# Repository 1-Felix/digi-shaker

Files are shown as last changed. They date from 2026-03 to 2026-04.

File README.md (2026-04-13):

<p align="center">
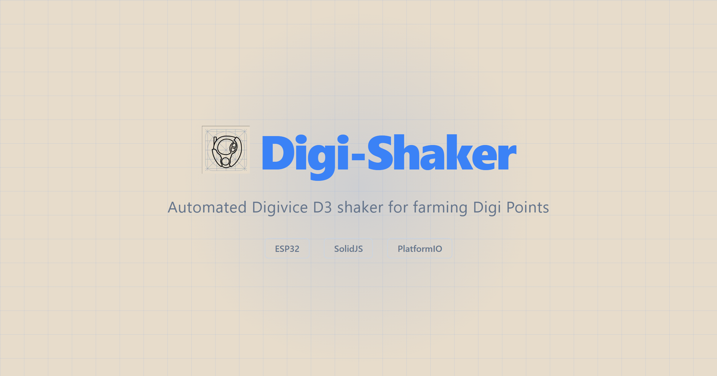
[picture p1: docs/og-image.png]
Digi-Shaker
  
</p>

<p align="center">
  <strong>Automated Digivice D3 shaker for farming Digi Points — controlled via web dashboard.</strong>
</p>

<p align="center">
  
</p>

---

An ESP32-powered physical device that shakes a Digivice D3 (Version 3 Japan edition) to farm Digi Points. Part of a larger reverse engineering project for the D3 game.

Features a 3D printed arm that holds the device, driven by an MG996R servo. Control via web dashboard with configurable shake patterns, calibration, and step tracking.

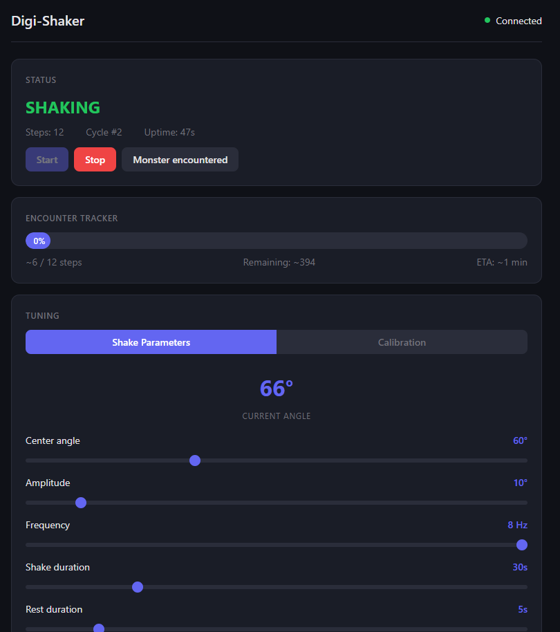
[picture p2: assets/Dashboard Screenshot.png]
Dashboard


Configure shake patterns, frequency, duration and rest periods from the web dashboard.

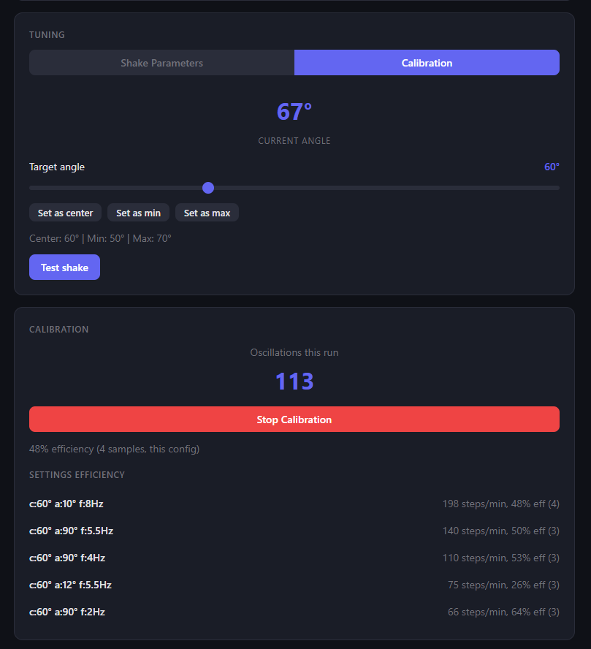
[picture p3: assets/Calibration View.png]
Calibration View


Step counting for accurate Digi Point tracking.

## Hardware

- **ESP32** (NodeMCU CH340 USB-C)
- **MG996R servo** driven by 3D printed arm cradle (in `models/`)

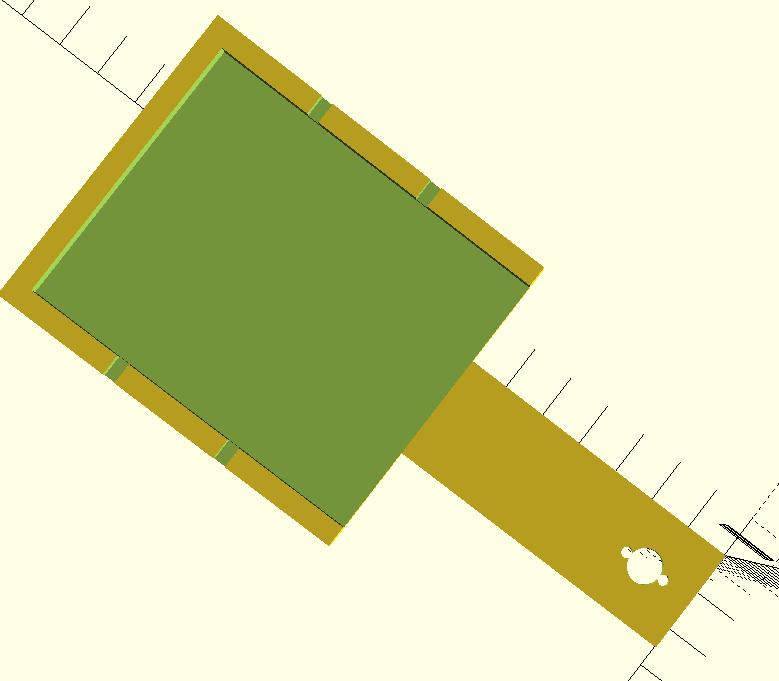
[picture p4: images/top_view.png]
Top View

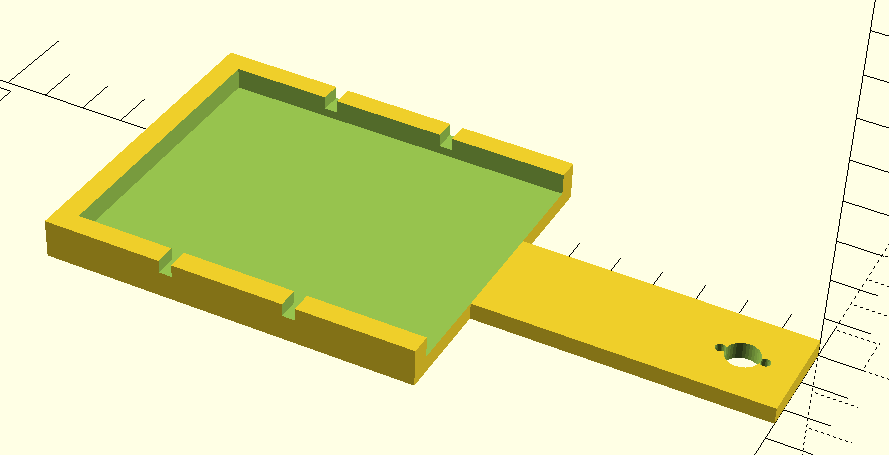
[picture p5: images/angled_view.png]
Angled View


<details>
<summary>3D printed parts</summary>

- Servo arm cradle (designed for MG996R)
- Device holder/clip
- Mounting base

Models in `models/` — designed for FDM printing with PLA.

</details>

## Quick Start

### 1. Flash the firmware

```bash
cd firmware
pio run upload
```

Configure WiFi credentials in `firmware/include/wifi_credentials.h` before building.

### 2. Run the dashboard

```bash
cd dashboard/ui
bun install
bun dev
```

Open http://localhost:5173 — the dashboard auto-discovers the device via mDNS or connect directly to `http://<device-ip>:81`.

### 3. Configure and start shaking

Set shake frequency, amplitude, and duration from the dashboard. The device will shake in cycles with rest periods.

## WebSocket Protocol

The dashboard communicates with the device over WebSocket on port 81.

```
┌──────────────┐    WS :81    ┌─────────────┐
│  Dashboard  │ ◀───────────▶ │ ESP32       │
│  (SolidJS)  │              │ + Servo     │
└──────────────┘              └─────────────┘
```

Messages are JSON — see `openspec/changes/remote-dashboard/specs/websocket-protocol/spec.md` for the full protocol spec.

## Architecture

```
┌─────────────────────────────────────────────────────────────┐
│                      Web Dashboard                         │
│  ┌─────────────┐  ┌──────────────┐  ┌─────────────────┐  │
│  │ StatusPanel │  │ ControlPanel │  │ CalibrationView  │  │
│  └─────────────┘  └──────────────┘  └─────────────────┘  │
└────────────────────────────┬────────────────────────────────┘
                             │ WebSocket
                             ▼
┌─────────────────────────────────────────────────────────────┐
│                         ESP32                               │
│  ┌──────────────┐  ┌───────────────┐  ┌────────────────┐  │
│  │ StateMachine │  │ ServoControl  │  │ StepCounter    │  │
│  │ IDLE/SHAKING │  │ MG996R driver │  │ Zero-crossing  │  │
│  └──────────────┘  └───────────────┘  └────────────────┘  │
│         │                  │                  │            │
│         └──────────────────┼──────────────────┘            │
│                            ▼                               │
│                    ┌─────────────┐                         │
│                    │   Servo     │ ◀── shakes D3 device    │
│                    └─────────────┘                         │
└─────────────────────────────────────────────────────────────┘
```

## Tech Stack

- **ESP32** — microcontroller
- **PlatformIO** — firmware build
- **Arduino** — firmware framework
- **SolidJS** — dashboard UI
- **WebSockets** — real-time control
- **OpenSCAD** — 3D models

## Development

```bash
# Firmware
cd firmware
pio run upload
pio monitor

# Dashboard
cd dashboard/ui
bun dev
```

## License

MIT

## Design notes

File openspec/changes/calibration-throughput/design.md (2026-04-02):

## Context

The calibration system stores efficiency ratio (actualSteps / oscillationCount) per config. The Settings Efficiency table sorts by ratio. But the user optimizes for **time-to-encounter** — the metric that matters is steps/minute throughput, not per-oscillation efficiency.

Currently, throughput can be computed from existing data: `freq × ratio × 60 × (shakeDur / (shakeDur + restDur))`. But this is theoretical — it doesn't account for servo lag, startup time, or physical constraints at high frequencies. Storing measured shaking duration per sample enables actual throughput measurement.

## Goals / Non-Goals

**Goals:**
- Compute and display throughput (steps/min) for all existing calibration data using config parameters
- Track elapsed shaking time (excluding rest/idle) on new calibration samples for measured throughput
- Make throughput the primary sort/comparison metric in the UI
- Use measured throughput when available, fall back to computed

**Non-Goals:**
- Firmware changes (ESP32 already broadcasts state in status messages)
- Changing the calibration collection workflow (start/stop/submit stays the same)
- Historical backfill of shaking duration for existing samples

## Decisions

### 1. Track shaking time on the backend, not the frontend

The backend already receives every ESP32 status update with `state` field. During a calibration run, the backend can accumulate time spent in `shaking` state by tracking state transitions. This is more accurate than frontend timing (no network latency skew) and requires no protocol changes.

**Alternative**: Frontend tracks time via `status.state` — rejected because backend already has the status stream and can track more precisely without round-trip latency.

### 2. Nullable `shaking_duration_s` column

Add `shaking_duration_s REAL` (nullable) to the `calibrations` table. Existing rows remain NULL. When duration is available, compute `measured_throughput = actualSteps / (shaking_duration_s / 60)`. When NULL, fall back to computed throughput from config params.

**Alternative**: Separate throughput table — rejected as unnecessary complexity for a single additional column.

### 3. Backend tracks calibration state per browser client

The calibration start/stop is initiated by a specific browser client. The backend needs to track which client is calibrating, when they started, and accumulate shaking seconds. A simple `Map<ws, CalibrationState>` keyed by WebSocket connection handles this.

State tracked per calibration run:
- `startedAt`: timestamp
- `shakingMs`: accumulated milliseconds in shaking state
- `lastShakingStart`: timestamp when current shaking interval began (null if resting/idle)

On each ESP32 status update, for any active calibration: if state transitioned to `shaking`, record `lastShakingStart`. If state transitioned away from `shaking`, add elapsed to `shakingMs`.

### 4. Throughput computation for existing data

For samples without `shaking_duration_s`:
```
computedThroughput = frequency × avgRatio × 60 × (shakeDuration / (shakeDuration + restDuration))
```

This uses the config params stored on the calibration sample and the config's average ratio. It's a per-config metric displayed in the efficiency table.

### 5. Frontend sends `startCalibration` / `stopCalibration` messages

New message types so the backend knows when to start/stop tracking shaking time. The existing `calibration` submit message includes the accumulated duration from the backend's tracking.

## Risks / Trade-offs

- **[Stale tracking on disconnect]** → If browser disconnects mid-calibration, the tracking state is lost. Acceptable since the user would need to restart calibration anyway.
- **[Clock precision]** → Using `Date.now()` for millisecond tracking. Sufficient for 30s+ calibration runs where we need ~1s accuracy.
- **[Computed vs measured mismatch]** → Users may see different throughput numbers for old (computed) vs new (measured) samples of the same config. The UI should indicate which is which.

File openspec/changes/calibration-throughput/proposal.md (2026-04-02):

## Why

The current calibration system only measures efficiency (steps per oscillation ratio), but the metric that actually matters is **throughput** — how many real steps the Digivice registers per minute. A config with lower efficiency but higher frequency can produce more steps/min than a high-efficiency slow config. Without throughput data, the user can't meaningfully compare settings to find the fastest path to an encounter.

## What Changes

- Compute and display **steps/minute throughput** for each calibration config, derived from existing data (frequency × ratio × duty cycle)
- Store **elapsed shaking time** (excluding rest/idle periods) on new calibration samples for measured throughput
- Sort the Settings Efficiency table by throughput (steps/min) instead of efficiency ratio
- Show throughput as the primary metric in the calibration comparison UI, with efficiency as secondary

## Capabilities

### New Capabilities
- `calibration-throughput`: Throughput calculation, storage, and display for calibration configs — both computed (from existing data) and measured (from new samples with tracked duration)

### Modified Capabilities

## Impact

- **Database**: `calibrations` table gets a new `shaking_duration_s` column (nullable for existing rows)
- **Backend**: Server tracks shaking time during calibration runs via ESP32 state transitions; enriches calibration responses with throughput
- **Frontend**: CalibrationPanel and EncounterTracker updated to display throughput; efficiency table re-sorted
- **No firmware changes** — ESP32 already broadcasts state in status messages

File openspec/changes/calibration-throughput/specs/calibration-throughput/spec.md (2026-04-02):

## ADDED Requirements

### Requirement: Shaking duration tracking
The system SHALL track elapsed shaking time (time spent in `shaking` state only, excluding rest and idle periods) during calibration runs. The backend SHALL start tracking when it receives a `startCalibration` message and stop when it receives a `stopCalibration` message from the same browser client.

#### Scenario: Normal calibration run with shaking and resting
- **WHEN** a calibration run spans 3 shake cycles (30s each) with 5s rest between them
- **THEN** the tracked shaking duration SHALL be ~90 seconds (excluding the 10s of rest)

#### Scenario: Calibration run where shaker is stopped mid-shake
- **WHEN** the user stops calibration while the servo is in shaking state
- **THEN** the system SHALL include the partial shaking interval in the total duration

#### Scenario: Browser disconnects during calibration
- **WHEN** the browser WebSocket disconnects while a calibration is active
- **THEN** the tracking state SHALL be discarded (no partial data stored)

### Requirement: Shaking duration storage
The system SHALL store `shaking_duration_s` (real, nullable) in the calibrations table. New calibration samples submitted via `stopCalibration` SHALL include the tracked shaking duration. Existing samples without duration SHALL have NULL for this field.

#### Scenario: New calibration sample with duration
- **WHEN** a calibration sample is submitted after a tracked run of 90 seconds of shaking
- **THEN** the sample SHALL be stored with `shaking_duration_s = 90`

#### Scenario: Existing sample without duration
- **WHEN** the system reads a calibration sample that was created before this feature
- **THEN** `shaking_duration_s` SHALL be NULL

### Requirement: Throughput computation
The system SHALL compute throughput (steps per minute) for each calibration config. When `shaking_duration_s` is available, throughput SHALL be `actualSteps / (shaking_duration_s / 60)`. When not available, throughput SHALL be computed as `frequency × avgRatio × 60 × (shakeDuration / (shakeDuration + restDuration))` using the config's stored parameters.

#### Scenario: Measured throughput from tracked duration
- **WHEN** a config has samples with `shaking_duration_s` recorded
- **THEN** throughput SHALL be calculated from the measured duration: `sum(actualSteps) / (sum(shaking_duration_s) / 60)`

#### Scenario: Computed throughput from config parameters
- **WHEN** a config has only samples without `shaking_duration_s` (legacy data)
- **THEN** throughput SHALL be estimated as `frequency × avgRatio × 60 × (shakeDuration / (shakeDuration + restDuration))`

### Requirement: Efficiency table sorted by throughput
The Settings Efficiency table SHALL sort configs by throughput (steps/min) descending instead of by efficiency ratio. Each config entry SHALL display both throughput and efficiency.

#### Scenario: Two configs with different throughput rankings
- **WHEN** Config A has 70% efficiency at 4Hz (throughput ~168 steps/min) and Config B has 40% efficiency at 8Hz (throughput ~192 steps/min)
- **THEN** Config B SHALL appear above Config A in the table

#### Scenario: Throughput display format
- **WHEN** a config has throughput of 168.4 steps/min and 70% efficiency
- **THEN** the entry SHALL display throughput rounded to nearest integer and efficiency as percentage (e.g., "168 steps/min, 70% eff")

### Requirement: Calibration WebSocket protocol additions
The browser SHALL send `startCalibration` message when beginning a calibration run and `stopCalibration` message when ending it. The backend SHALL respond to `stopCalibration` with the accumulated shaking duration. The existing `calibration` submit message SHALL accept an optional `shakingDurationS` field.

#### Scenario: Start calibration message
- **WHEN** the user clicks "Start Calibration"
- **THEN** the browser SHALL send `{ type: "startCalibration" }` to the backend

#### Scenario: Stop calibration message and response
- **WHEN** the user clicks "Stop Calibration"
- **THEN** the browser SHALL send `{ type: "stopCalibration" }` and the backend SHALL respond with `{ type: "calibrationStopped", shakingDurationS: <number> }`

#### Scenario: Submit with duration
- **WHEN** the user submits a calibration with actual steps after receiving the shaking duration
- **THEN** the `calibration` message SHALL include `shakingDurationS` alongside `oscillationCount` and `actualSteps`

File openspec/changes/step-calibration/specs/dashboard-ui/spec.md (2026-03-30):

## ADDED Requirements

### Requirement: Calibration panel
The dashboard SHALL include a calibration panel for measuring and recording the step registration ratio.

#### Scenario: Start calibration
- **WHEN** the user clicks "Start Calibration"
- **THEN** the system SHALL record the current stepCount, start the shaker if idle, and begin tracking oscillations

#### Scenario: Stop calibration
- **WHEN** the user clicks "Stop Calibration" during a calibration run
- **THEN** the shaker SHALL stop and the UI SHALL display the oscillation count (current stepCount minus start stepCount) and prompt for actual Digivice steps

#### Scenario: Submit actual steps
- **WHEN** the user enters the actual step count and clicks "Submit"
- **THEN** the calibration sample SHALL be sent to the backend and a success toast SHALL appear

#### Scenario: Validation
- **WHEN** the user submits an actual step count that is zero, negative, or greater than the oscillation count
- **THEN** the UI SHALL show an error and not submit

### Requirement: Current ratio display
The calibration panel SHALL display the current calibration ratio and how it was determined.

#### Scenario: Config-specific ratio
- **WHEN** calibrations exist for the current parameter set
- **THEN** the panel SHALL display the ratio and sample count for the current config

#### Scenario: Global fallback display
- **WHEN** using the global average fallback
- **THEN** the panel SHALL indicate that the ratio is a global average, not config-specific

### Requirement: Settings efficiency comparison
The calibration panel SHALL display a comparison of calibration efficiency across different parameter configurations.

#### Scenario: Multiple configs calibrated
- **WHEN** calibration samples exist for more than one parameter configuration
- **THEN** the panel SHALL show each config with its average efficiency percentage and sample count, sorted by efficiency

#### Scenario: Single config
- **WHEN** calibrations exist for only one config
- **THEN** only that config's efficiency SHALL be shown

### Requirement: Calibration history management
The calibration panel SHALL allow viewing and deleting individual calibration samples.

#### Scenario: View samples
- **WHEN** the user expands a config in the efficiency comparison
- **THEN** individual samples SHALL be visible with their oscillation count, actual steps, and ratio

#### Scenario: Delete sample
- **WHEN** the user clicks delete on a calibration sample
- **THEN** the sample SHALL be removed and the ratio recalculated

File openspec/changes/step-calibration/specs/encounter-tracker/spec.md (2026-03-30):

## MODIFIED Requirements

### Requirement: Encounter probability display
The dashboard SHALL display the cumulative probability of a monster encounter based on the **calibrated** step count (raw oscillations multiplied by the calibration ratio).

#### Scenario: Below first threshold
- **WHEN** the calibrated step count is below 400
- **THEN** the encounter probability SHALL display as 0% with a progress bar showing distance to 400

#### Scenario: Cumulative probability at thresholds
- **WHEN** the calibrated step count reaches 400, 450, 500, or 550
- **THEN** the encounter probability SHALL display the cumulative value (40%, 60%, 90%, 100%)

#### Scenario: Display raw and calibrated
- **WHEN** a calibration ratio other than 1.0 is active
- **THEN** the display SHALL show both calibrated and raw counts (e.g., "~87 / 120 steps")

#### Scenario: No calibration
- **WHEN** no calibration data exists (ratio is 1.0)
- **THEN** the display SHALL show the raw step count without a calibrated value

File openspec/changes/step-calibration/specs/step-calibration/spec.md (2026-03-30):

## ADDED Requirements

### Requirement: Calibration data persistence
The backend SHALL store calibration samples in a `calibrations` SQLite table with columns: id, created_at, oscillation_count, actual_steps, ratio, center_angle, amplitude, frequency.

#### Scenario: Table creation
- **WHEN** the backend starts and the calibrations table does not exist
- **THEN** it SHALL be created with the schema above

#### Scenario: Sample storage
- **WHEN** a calibration sample is submitted with oscillation_count and actual_steps
- **THEN** the backend SHALL store it with the current shake parameters and computed ratio (actual_steps / oscillation_count)

### Requirement: Calibration ratio lookup
The backend SHALL provide a calibration ratio using a three-tier fallback: exact config match, global average, or 1.0.

#### Scenario: Exact config match
- **WHEN** calibration samples exist for the current center_angle, amplitude, and frequency
- **THEN** the ratio SHALL be the average of matching samples' ratios

#### Scenario: Global fallback
- **WHEN** no calibration samples match the current config but other samples exist
- **THEN** the ratio SHALL be the average of all samples' ratios

#### Scenario: No calibrations
- **WHEN** no calibration samples exist at all
- **THEN** the ratio SHALL be 1.0

### Requirement: Calibration submission via WebSocket
The backend SHALL accept calibration submissions over the browser WebSocket.

#### Scenario: Submit calibration
- **WHEN** the browser sends `{ "type": "calibration", "oscillationCount": <number>, "actualSteps": <number> }`
- **THEN** the backend SHALL store the sample with the current ESP32 parameters and respond with the updated ratio

### Requirement: Calibration history via WebSocket
The backend SHALL provide calibration history and current ratio to browser clients.

#### Scenario: Request calibration data
- **WHEN** the browser sends `{ "type": "getCalibration" }`
- **THEN** the backend SHALL respond with the current ratio, sample count, and per-config efficiency breakdown

#### Scenario: Ratio included in status
- **WHEN** the backend enriches an ESP32 status message for browser clients
- **THEN** it SHALL include the current calibration ratio and calibrated step count

### Requirement: Delete calibration sample
The backend SHALL support deleting individual calibration samples.

#### Scenario: Delete sample
- **WHEN** the browser sends `{ "type": "deleteCalibration", "id": <number> }`
- **THEN** the backend SHALL remove that sample and respond with the updated ratio

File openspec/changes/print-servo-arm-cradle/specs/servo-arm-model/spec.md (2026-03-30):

## ADDED Requirements

### Requirement: Parametric OpenSCAD model
The project SHALL include an OpenSCAD file at `models/servo-arm-cradle.scad` that generates a 3D-printable servo arm with integrated Digivice cradle. All key dimensions SHALL be defined as parameters at the top of the file.

#### Scenario: Adjustable parameters
- **WHEN** a user opens the .scad file
- **THEN** the following parameters SHALL be editable at the top of the file: `digivice_length` (default 75), `digivice_width` (default 60), `digivice_depth` (default 20), `arm_length` (default 100), `arm_width` (default 25), `arm_thickness` (default 4), `wall_height` (default 5), `wall_thickness` (default 5), `clearance` (default 1), `horn_screw_spacing` (default 10), `horn_screw_diameter` (default 2.5)

#### Scenario: Preview renders correctly
- **WHEN** a user presses F5 (preview) in OpenSCAD
- **THEN** the model SHALL render a single solid body showing the arm, cradle walls, and servo horn mount holes

### Requirement: Servo horn mount
The arm SHALL include a flat mounting area on one end with two through-holes spaced to match the MG996R stock servo horn screw pattern. The holes SHALL have a diameter of 2.5mm (for M2 screws with clearance).

#### Scenario: Horn screw holes are present
- **WHEN** the STL is sliced in a slicer
- **THEN** two cylindrical through-holes SHALL be visible on the servo end, spaced 10mm apart (center to center), each 2.5mm in diameter

### Requirement: Digivice cradle pocket
The arm SHALL include a rectangular pocket on the opposite end from the servo mount. The pocket inner dimensions SHALL be `digivice_length + 2*clearance` by `digivice_width + 2*clearance`. Walls SHALL rise `wall_height` mm above the arm surface on three sides, with one short side open for sliding the device in.

#### Scenario: Digivice fits in pocket
- **WHEN** a Digivice D3 V3 (75 x 60 mm) is placed into the printed cradle
- **THEN** it SHALL fit with approximately 1mm clearance on each side

#### Scenario: One open side for insertion
- **WHEN** viewing the cradle from above
- **THEN** one of the short sides (60mm side) SHALL have no wall, allowing the Digivice to slide in

### Requirement: Rubber band retention slots
The cradle walls SHALL include notches/slots to allow rubber bands to be wrapped around the cradle to secure the Digivice. There SHALL be at least two slots on each long wall.

#### Scenario: Rubber band slots present
- **WHEN** examining the printed cradle walls
- **THEN** each long wall SHALL have at least two U-shaped notches (approximately 3mm wide, 3mm deep) cut into the top edge of the wall

### Requirement: Print-friendly geometry
The model SHALL be designed to print flat on a build plate without supports. All surfaces SHALL be flat-bottomed. No overhangs SHALL exceed 45 degrees.

#### Scenario: No supports needed in slicer
- **WHEN** the STL is imported into a slicer (e.g., Cura, PrusaSlicer) with the flat bottom on the build plate
- **THEN** the slicer SHALL report no support material needed at default overhang settings (45°)

### Requirement: STL export
The project SHALL include a pre-exported STL file at `models/servo-arm-cradle.stl` ready for direct slicing and printing.

#### Scenario: STL file is valid
- **WHEN** the STL file is opened in a slicer
- **THEN** it SHALL be a valid, manifold mesh with no errors

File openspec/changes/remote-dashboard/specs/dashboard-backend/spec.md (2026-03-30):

## ADDED Requirements

### Requirement: Hono HTTP server
The dashboard backend SHALL run a Hono server on Bun, listening on port 3000 (configurable via `PORT` environment variable).

#### Scenario: Server starts
- **WHEN** the dashboard application starts
- **THEN** the Hono server SHALL listen on the configured port and serve the static SolidJS build files

#### Scenario: Static file serving
- **WHEN** a browser requests `/` or any UI route
- **THEN** the server SHALL serve the SolidJS application's `index.html` and associated assets

### Requirement: ESP32 WebSocket client
The backend SHALL maintain a WebSocket connection to the ESP32 as a client.

#### Scenario: Connect to ESP32
- **WHEN** the backend starts
- **THEN** it SHALL connect to the ESP32 WebSocket server at the address specified by the `ESP32_HOST` environment variable (default: `digi-shaker.local`) on port 81

#### Scenario: Reconnection
- **WHEN** the WebSocket connection to the ESP32 drops
- **THEN** the backend SHALL reconnect with exponential backoff starting at 1 second, capping at 30 seconds

#### Scenario: Connection status tracking
- **WHEN** the ESP32 connection state changes (connected/disconnected)
- **THEN** the backend SHALL include the connection status in messages to browser clients

### Requirement: Browser WebSocket server
The backend SHALL accept WebSocket connections from browser dashboard clients.

#### Scenario: Browser connects
- **WHEN** a browser client connects to `ws://<host>:3000/ws`
- **THEN** the backend SHALL accept the connection and begin relaying ESP32 status messages

#### Scenario: Multiple browsers
- **WHEN** multiple browser clients connect simultaneously
- **THEN** all clients SHALL receive the same status broadcasts

#### Scenario: Command relay
- **WHEN** a browser client sends a command message
- **THEN** the backend SHALL forward it to the ESP32 over the ESP32 WebSocket connection

#### Scenario: ESP32 offline
- **WHEN** a browser sends a command but the ESP32 is disconnected
- **THEN** the backend SHALL respond with an error message: `{ "type": "error", "message": "ESP32 not connected" }`

### Requirement: Status enrichment
The backend SHALL enrich ESP32 status messages with encounter probability data before relaying to browsers.

#### Scenario: Probability calculation
- **WHEN** the backend receives a status message from the ESP32
- **THEN** it SHALL calculate the cumulative encounter probability based on shake count and append it to the message before sending to browsers

#### Scenario: Configurable thresholds
- **WHEN** encounter probability thresholds are defined in the backend configuration
- **THEN** the backend SHALL use those thresholds for probability calculation instead of hardcoded defaults

### Requirement: SQLite stats persistence
The backend SHALL persist shake session data in a SQLite database using `bun:sqlite`.

#### Scenario: Database initialization
- **WHEN** the backend starts and no database file exists at `data/shaker.sqlite`
- **THEN** it SHALL create the database and initialize the schema

#### Scenario: Session recording
- **WHEN** a shake cycle completes (ESP32 transitions from SHAKING to RESTING)
- **THEN** the backend SHALL record the session with: timestamp, shake count at start, shake count at end, duration, and active parameters

#### Scenario: Counter reset recording
- **WHEN** the user resets the shake counter (indicating a monster encounter)
- **THEN** the backend SHALL record the encounter with: timestamp and total shakes before reset

#### Scenario: History query
- **WHEN** a browser client requests session history
- **THEN** the backend SHALL query the database and return sessions grouped by day with totals

### Requirement: Last-known config resend
The backend SHALL persist the last-known parameter configuration and resend it to the ESP32 on reconnection.

#### Scenario: Config persistence
- **WHEN** the user changes parameters via the dashboard
- **THEN** the backend SHALL store the parameters in the database

#### Scenario: Resend on reconnect
- **WHEN** the ESP32 reconnects after a reboot
- **THEN** the backend SHALL send the last-known parameter configuration to the ESP32

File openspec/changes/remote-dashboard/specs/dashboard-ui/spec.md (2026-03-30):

## ADDED Requirements

### Requirement: Connection status indicator
The dashboard SHALL display the connection status to both the backend and the ESP32.

#### Scenario: Fully connected
- **WHEN** the browser is connected to the backend and the backend is connected to the ESP32
- **THEN** a green indicator SHALL display "Connected"

#### Scenario: ESP32 disconnected
- **WHEN** the browser is connected to the backend but the ESP32 is offline
- **THEN** a yellow indicator SHALL display "ESP32 Offline"

#### Scenario: Backend disconnected
- **WHEN** the browser loses connection to the backend
- **THEN** a red indicator SHALL display "Disconnected" and the browser SHALL attempt to reconnect

### Requirement: Status panel
The dashboard SHALL display the current shaker state prominently.

#### Scenario: Shaking state
- **WHEN** the ESP32 is in SHAKING state
- **THEN** the panel SHALL display "SHAKING", the current cycle number, and the uptime

#### Scenario: Resting state
- **WHEN** the ESP32 is in RESTING state
- **THEN** the panel SHALL display "RESTING" and the time remaining until the next shake cycle

#### Scenario: Idle state
- **WHEN** the ESP32 is in IDLE state
- **THEN** the panel SHALL display "IDLE"

#### Scenario: Tuning state
- **WHEN** the ESP32 is in TUNING state
- **THEN** the panel SHALL display "TUNING" and the current servo angle

### Requirement: Start and stop controls
The dashboard SHALL provide buttons to start and stop the shaker.

#### Scenario: Start button
- **WHEN** the shaker is in IDLE or TUNING state and the user clicks "Start"
- **THEN** a start command SHALL be sent to the ESP32

#### Scenario: Stop button
- **WHEN** the shaker is in SHAKING, RESTING, or TUNING state and the user clicks "Stop"
- **THEN** a stop command SHALL be sent to the ESP32

### Requirement: Parameter tuning controls
The dashboard SHALL provide slider controls to adjust shake parameters in real time.

#### Scenario: Center angle slider
- **WHEN** the user adjusts the center angle slider
- **THEN** the new value SHALL be sent to the ESP32 and the slider SHALL display the current value in degrees

#### Scenario: Amplitude slider
- **WHEN** the user adjusts the amplitude slider
- **THEN** the new value SHALL be sent to the ESP32

#### Scenario: Frequency slider
- **WHEN** the user adjusts the frequency slider
- **THEN** the new value SHALL be sent to the ESP32 and the slider SHALL display the value in Hz

#### Scenario: Shake duration slider
- **WHEN** the user adjusts the shake duration slider
- **THEN** the new value SHALL be sent to the ESP32

#### Scenario: Rest duration slider
- **WHEN** the user adjusts the rest duration slider
- **THEN** the new value SHALL be sent to the ESP32

#### Scenario: Live feedback
- **WHEN** any parameter slider is adjusted
- **THEN** the change SHALL be sent within 100ms and the current servo angle readout SHALL reflect the new parameters

### Requirement: Tuning mode UI
The dashboard SHALL provide a dedicated tuning interface for precise servo calibration.

#### Scenario: Enter tuning mode
- **WHEN** the user switches to tuning mode
- **THEN** a tune command SHALL be sent to the ESP32 and the tuning controls SHALL appear

#### Scenario: Target angle slider
- **WHEN** the user adjusts the target angle slider in tuning mode
- **THEN** the servo SHALL move to the specified angle slowly

#### Scenario: Set as center button
- **WHEN** the user clicks "Set as center" in tuning mode
- **THEN** the current target angle SHALL be saved as the center angle parameter

#### Scenario: Set as min button
- **WHEN** the user clicks "Set as min" in tuning mode
- **THEN** the amplitude SHALL be recalculated as `center - currentAngle`

#### Scenario: Set as max button
- **WHEN** the user clicks "Set as max" in tuning mode
- **THEN** the amplitude SHALL be recalculated as `currentAngle - center`

#### Scenario: Test shake button
- **WHEN** the user clicks "Test shake" in tuning mode
- **THEN** a start command SHALL be sent with the current tuning parameters to preview the motion

### Requirement: Counter reset
The dashboard SHALL provide a way to reset the shake counter, indicating a monster encounter occurred.

#### Scenario: Reset button
- **WHEN** the user clicks "Reset counter" (or "Monster encountered")
- **THEN** a resetCount command SHALL be sent to the ESP32 and the encounter SHALL be recorded in the backend

### Requirement: Session history display
The dashboard SHALL display historical shake session data.

#### Scenario: Daily summary
- **WHEN** the history panel is visible
- **THEN** it SHALL show sessions grouped by day with total shakes per day

#### Scenario: Encounter markers
- **WHEN** a monster encounter was recorded on a given day
- **THEN** it SHALL be marked in the history alongside the shake count at which it occurred

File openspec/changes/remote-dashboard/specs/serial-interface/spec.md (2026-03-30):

## MODIFIED Requirements

### Requirement: Serial initialization
The system SHALL initialize the serial interface at 115200 baud during setup.

#### Scenario: Serial starts on boot
- **WHEN** the ESP32 boots up
- **THEN** the serial interface SHALL be initialized and print a startup message including the project name, configured shake parameters, and Wi-Fi connection status

### Requirement: Shake cycle logging
The system SHALL print status messages to serial when shake state changes.

#### Scenario: Shake start logged
- **WHEN** a shake cycle begins
- **THEN** the system SHALL print a message indicating the shake cycle number and start time

#### Scenario: Rest start logged
- **WHEN** a rest period begins
- **THEN** the system SHALL print a message indicating the rest period and total shakes completed

## ADDED Requirements

### Requirement: Wi-Fi status logging
The system SHALL print Wi-Fi connection events to serial.

#### Scenario: Connection logged
- **WHEN** the ESP32 connects to Wi-Fi
- **THEN** it SHALL print the SSID, IP address, and mDNS hostname to serial

#### Scenario: Disconnection logged
- **WHEN** the Wi-Fi connection drops
- **THEN** it SHALL print a disconnection warning to serial

### Requirement: WebSocket event logging
The system SHALL print WebSocket connection events to serial.

#### Scenario: Client connected
- **WHEN** a WebSocket client connects
- **THEN** the system SHALL print a message indicating a client connected

#### Scenario: Command received
- **WHEN** a WebSocket command is received
- **THEN** the system SHALL print the command type to serial for debugging

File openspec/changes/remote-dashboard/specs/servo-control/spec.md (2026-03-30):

## MODIFIED Requirements

### Requirement: Angle control
The system SHALL provide a function to set the servo angle between 0 degrees and 180 degrees. The angle SHALL be clamped to valid range. The function SHALL be used by both the shake pattern and the tuning mode.

#### Scenario: Set valid angle
- **WHEN** the servo is commanded to move to 45 degrees
- **THEN** the servo SHALL move to the 45 degree position

#### Scenario: Clamp out-of-range angle
- **WHEN** the servo is commanded to move to 200 degrees
- **THEN** the servo SHALL clamp to 180 degrees and move there

## ADDED Requirements

### Requirement: Extended state machine
The servo control system SHALL support four states: IDLE, SHAKING, RESTING, and TUNING.

#### Scenario: IDLE state
- **WHEN** the system is in IDLE state
- **THEN** the servo SHALL be centered and detached (no PWM signal)

#### Scenario: SHAKING state
- **WHEN** the system is in SHAKING state
- **THEN** the servo SHALL execute the configured oscillation pattern

#### Scenario: RESTING state
- **WHEN** the system is in RESTING state
- **THEN** the servo SHALL be centered and detached until the rest period elapses

#### Scenario: TUNING state
- **WHEN** the system is in TUNING state
- **THEN** the servo SHALL hold at the target angle and remain attached

### Requirement: Shake counter
The system SHALL maintain a count of completed shake cycles since the last reset.

#### Scenario: Count increments
- **WHEN** a shake duration elapses and the system transitions to RESTING
- **THEN** the shake counter SHALL increment by one

#### Scenario: Count reset
- **WHEN** a resetCount command is received
- **THEN** the shake counter SHALL reset to 0

#### Scenario: Count survives state changes
- **WHEN** the system transitions between IDLE, TUNING, and SHAKING states
- **THEN** the shake counter SHALL retain its value (not reset)

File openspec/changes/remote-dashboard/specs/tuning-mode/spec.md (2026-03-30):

## ADDED Requirements

### Requirement: Tuning state
The firmware SHALL support a TUNING state in which the servo moves slowly to a target angle and holds position for calibration.

#### Scenario: Enter tuning mode
- **WHEN** a tune command is received
- **THEN** the system SHALL transition to TUNING state and the servo SHALL attach if not already attached

#### Scenario: Set target angle in tuning mode
- **WHEN** the system is in TUNING state and receives a target angle
- **THEN** the servo SHALL move to that angle at a reduced speed (stepping 1 degree per 20ms) and hold

#### Scenario: Angle clamping in tuning mode
- **WHEN** a target angle outside 0-180 degrees is requested
- **THEN** the angle SHALL be clamped to the valid range

#### Scenario: Exit tuning via start
- **WHEN** a start command is received while in TUNING state
- **THEN** the system SHALL transition to SHAKING state and begin a shake cycle with current parameters

#### Scenario: Exit tuning via stop
- **WHEN** a stop command is received while in TUNING state
- **THEN** the system SHALL transition to IDLE state, center the servo, and detach

### Requirement: Slow servo movement
In TUNING state, the servo SHALL move gradually to the target angle rather than jumping instantly.

#### Scenario: Gradual movement
- **WHEN** the servo is at 90 degrees and a target of 60 degrees is set
- **THEN** the servo SHALL step from 90 to 60 one degree at a time with a 20ms delay between steps

#### Scenario: New target during movement
- **WHEN** a new target angle is received while the servo is still moving toward a previous target
- **THEN** the servo SHALL change direction toward the new target from its current position

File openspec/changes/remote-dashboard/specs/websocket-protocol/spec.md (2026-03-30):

## ADDED Requirements

### Requirement: ESP32 WebSocket server
The ESP32 SHALL run a WebSocket server on port 81 that accepts connections from the dashboard backend.

#### Scenario: Server starts after Wi-Fi
- **WHEN** the ESP32 successfully connects to Wi-Fi
- **THEN** a WebSocket server SHALL start listening on port 81

#### Scenario: Client connects
- **WHEN** the backend connects to the ESP32 WebSocket server
- **THEN** the ESP32 SHALL accept the connection and begin sending status messages

#### Scenario: Connection limit
- **WHEN** more than 2 WebSocket clients attempt to connect
- **THEN** the ESP32 SHALL reject additional connections to preserve memory

### Requirement: Status reporting
The ESP32 SHALL send periodic JSON status messages to all connected WebSocket clients.

#### Scenario: Periodic status broadcast
- **WHEN** a WebSocket client is connected
- **THEN** the ESP32 SHALL send a status message every 500ms containing: current state, shake count, current servo angle, active parameters, and uptime in milliseconds

#### Scenario: Status message format
- **WHEN** the ESP32 sends a status message
- **THEN** it SHALL be a JSON object with the structure: `{ "type": "status", "state": "<state>", "shakeCount": <number>, "angle": <number>, "params": { "center": <number>, "amplitude": <number>, "frequency": <number>, "shakeDuration": <number>, "restDuration": <number> }, "uptimeMs": <number> }`

### Requirement: Command reception
The ESP32 SHALL accept JSON command messages from connected WebSocket clients and execute them.

#### Scenario: Start command
- **WHEN** the ESP32 receives `{ "type": "command", "action": "start" }`
- **THEN** it SHALL transition to the SHAKING state and begin a shake cycle

#### Scenario: Stop command
- **WHEN** the ESP32 receives `{ "type": "command", "action": "stop" }`
- **THEN** it SHALL transition to the IDLE state, center the servo, and detach it

#### Scenario: Tune command
- **WHEN** the ESP32 receives `{ "type": "command", "action": "tune" }`
- **THEN** it SHALL transition to the TUNING state

#### Scenario: Config update
- **WHEN** the ESP32 receives `{ "type": "config", "params": { ... } }`
- **THEN** it SHALL update the active shake parameters to the provided values and use them for subsequent shake cycles

#### Scenario: Tune angle
- **WHEN** the ESP32 receives `{ "type": "tune", "angle": <number> }` while in TUNING state
- **THEN** the servo SHALL move slowly to the specified angle and hold

#### Scenario: Reset count
- **WHEN** the ESP32 receives `{ "type": "command", "action": "resetCount" }`
- **THEN** the shake counter SHALL reset to 0

### Requirement: Invalid message handling
The ESP32 SHALL ignore malformed or unknown WebSocket messages without crashing.

#### Scenario: Malformed JSON
- **WHEN** the ESP32 receives a non-JSON or malformed WebSocket message
- **THEN** it SHALL ignore the message and log a warning to serial

#### Scenario: Unknown message type
- **WHEN** the ESP32 receives a JSON message with an unrecognized `type` field
- **THEN** it SHALL ignore the message

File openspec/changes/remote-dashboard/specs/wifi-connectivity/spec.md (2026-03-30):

## ADDED Requirements

### Requirement: Wi-Fi station mode
The ESP32 SHALL connect to a home Wi-Fi network in station mode using credentials defined in the firmware configuration.

#### Scenario: Successful connection on boot
- **WHEN** the ESP32 boots with valid SSID and password configured
- **THEN** the ESP32 SHALL connect to the Wi-Fi network and print its IP address to serial

#### Scenario: Connection failure
- **WHEN** the ESP32 cannot connect to the configured network within 10 seconds
- **THEN** the ESP32 SHALL print an error to serial and retry every 5 seconds

#### Scenario: Reconnection after drop
- **WHEN** the Wi-Fi connection drops while the system is running
- **THEN** the ESP32 SHALL attempt to reconnect automatically and continue the current shake cycle uninterrupted

### Requirement: Wi-Fi credentials configuration
The firmware SHALL read Wi-Fi credentials from a `wifi_credentials.h` file that is excluded from version control via `.gitignore`.

#### Scenario: Credentials file exists
- **WHEN** `include/wifi_credentials.h` defines `WIFI_SSID` and `WIFI_PASSWORD`
- **THEN** the firmware SHALL compile and use those credentials for Wi-Fi connection

#### Scenario: Credentials file missing
- **WHEN** `include/wifi_credentials.h` does not exist
- **THEN** the firmware SHALL fail to compile with a clear error indicating the file is missing

### Requirement: mDNS hostname
The ESP32 SHALL register an mDNS hostname so the backend can discover it without knowing its IP address.

#### Scenario: mDNS registration
- **WHEN** the ESP32 connects to Wi-Fi
- **THEN** it SHALL register the mDNS hostname `digi-shaker` so it is reachable at `digi-shaker.local`

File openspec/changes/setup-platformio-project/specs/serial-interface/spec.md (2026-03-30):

## ADDED Requirements

### Requirement: Serial initialization
The system SHALL initialize the serial interface at 115200 baud during setup.

#### Scenario: Serial starts on boot
- **WHEN** the ESP32 boots up
- **THEN** the serial interface SHALL be initialized and print a startup message including the project name and configured shake parameters

### Requirement: Shake cycle logging
The system SHALL print status messages to serial when shake state changes.

#### Scenario: Shake start logged
- **WHEN** a shake cycle begins
- **THEN** the system SHALL print a message indicating the shake cycle number and start time

#### Scenario: Rest start logged
- **WHEN** a rest period begins
- **THEN** the system SHALL print a message indicating the rest period and total shakes completed

### Requirement: Shake counter
The system SHALL maintain a count of completed shake cycles since boot and report it via serial.

#### Scenario: Count increments
- **WHEN** a shake cycle completes
- **THEN** the internal counter SHALL increment by one and be included in the next serial status message

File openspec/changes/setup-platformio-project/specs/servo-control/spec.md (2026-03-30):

## ADDED Requirements

### Requirement: Servo initialization
The system SHALL initialize the MG996R servo on GPIO 13 using the ESP32Servo library during setup. The servo SHALL be attached with configurable minimum and maximum pulse widths (default 500µs and 2400µs).

#### Scenario: Servo attaches on boot
- **WHEN** the ESP32 boots up
- **THEN** the servo SHALL be attached to GPIO 13 and move to the center position (90°)

#### Scenario: Custom pulse range
- **WHEN** `min_pulse_us` and `max_pulse_us` are defined in config.h
- **THEN** the servo SHALL use those values for its pulse width range instead of defaults

### Requirement: Angle control
The system SHALL provide a function to set the servo angle between 0° and 180°. The angle SHALL be clamped to valid range.

#### Scenario: Set valid angle
- **WHEN** the servo is commanded to move to 45°
- **THEN** the servo SHALL move to 45° position

#### Scenario: Clamp out-of-range angle
- **WHEN** the servo is commanded to move to 200°
- **THEN** the servo SHALL clamp to 180° and move there

### Requirement: Safe detach
The system SHALL provide a way to detach the servo (stop sending PWM pulses) to reduce power draw and servo buzz during rest periods.

#### Scenario: Detach during rest
- **WHEN** the shake pattern enters a rest period
- **THEN** the servo SHALL be detached (no PWM signal sent) until the next shake cycle begins

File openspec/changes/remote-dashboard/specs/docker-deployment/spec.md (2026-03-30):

## ADDED Requirements

### Requirement: Dockerfile
The dashboard SHALL include a Dockerfile that builds a production-ready container image.

#### Scenario: Build image
- **WHEN** `docker build -t digi-shaker dashboard/` is run from the repo root
- **THEN** a container image SHALL be produced containing the Bun runtime, compiled server, and built SolidJS assets

#### Scenario: Container startup
- **WHEN** the container starts
- **THEN** the Hono server SHALL listen on port 3000 and serve the dashboard

#### Scenario: Data volume
- **WHEN** the container is run with a volume mount at `/app/data`
- **THEN** the SQLite database SHALL be persisted in that volume

### Requirement: Docker Compose example
The repository SHALL include a `docker-compose.example.yml` for easy deployment.

#### Scenario: Example file
- **WHEN** a user copies `docker-compose.example.yml` to `docker-compose.yml`
- **THEN** they SHALL only need to set the `ESP32_HOST` environment variable to deploy

#### Scenario: Volume configuration
- **WHEN** the docker-compose file is used
- **THEN** it SHALL mount a local `./data` directory to `/app/data` for SQLite persistence

### Requirement: GitHub Actions CI
The repository SHALL include a GitHub Actions workflow that builds and publishes the Docker image.

#### Scenario: Build on push to main
- **WHEN** code is pushed to the `main` branch
- **THEN** the workflow SHALL build the Docker image from `dashboard/Dockerfile`

#### Scenario: Publish to GHCR
- **WHEN** the Docker image is built successfully
- **THEN** the workflow SHALL push it to GitHub Container Registry (`ghcr.io`)

#### Scenario: Tag strategy
- **WHEN** the image is published
- **THEN** it SHALL be tagged with `latest` and the short commit SHA

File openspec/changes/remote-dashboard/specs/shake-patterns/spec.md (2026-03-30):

## MODIFIED Requirements

### Requirement: Configurable shake parameters
The system SHALL expose the following shake parameters as constants in `include/config.h` that serve as defaults. At runtime, parameters SHALL be overridable via WebSocket commands without recompiling.
- `SHAKE_CENTER_ANGLE`: center position in degrees (default 90)
- `SHAKE_AMPLITUDE`: degrees of sweep from center in each direction (default 35)
- `SHAKE_FREQUENCY_HZ`: oscillation frequency in Hz (default 3.0)
- `SHAKE_DURATION_S`: how long to shake in seconds (default 30)
- `SHAKE_REST_S`: rest period between shake cycles in seconds (default 5)

#### Scenario: Parameters defined in config
- **WHEN** a developer opens `include/config.h`
- **THEN** all shake parameters SHALL be visible as named constants with documented defaults

#### Scenario: Runtime parameter update
- **WHEN** a config update message is received via WebSocket with new parameter values
- **THEN** the active parameters SHALL be updated in memory and used for subsequent shake cycles

#### Scenario: Defaults on boot
- **WHEN** the ESP32 boots without receiving a config update
- **THEN** it SHALL use the compile-time defaults from `config.h`

### Requirement: Vigorous oscillation pattern
The system SHALL oscillate the servo between `center - amplitude` and `center + amplitude` at the configured frequency, using runtime parameter values. The motion SHALL use a sinusoidal wave pattern for smooth reversals.

#### Scenario: Shake at default settings
- **WHEN** the shake cycle is active with default parameters
- **THEN** the servo SHALL sweep between 55 degrees and 125 degrees approximately 3 times per second

#### Scenario: Smooth direction change
- **WHEN** the servo reaches the end of a sweep
- **THEN** it SHALL reverse direction without abrupt stops (smooth acceleration/deceleration)

#### Scenario: Parameter change mid-shake
- **WHEN** parameters are updated while a shake cycle is active
- **THEN** the new parameters SHALL take effect on the next loop iteration without restarting the cycle

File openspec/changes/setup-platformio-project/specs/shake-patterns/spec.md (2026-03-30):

## ADDED Requirements

### Requirement: Configurable shake parameters
The system SHALL expose the following shake parameters as constants in `include/config.h`:
- `SHAKE_CENTER_ANGLE`: center position in degrees (default 90)
- `SHAKE_AMPLITUDE`: degrees of sweep from center in each direction (default 35)
- `SHAKE_FREQUENCY_HZ`: oscillation frequency in Hz (default 3.0)
- `SHAKE_DURATION_S`: how long to shake in seconds (default 30)
- `SHAKE_REST_S`: rest period between shake cycles in seconds (default 5)

#### Scenario: Parameters defined in config
- **WHEN** a developer opens `include/config.h`
- **THEN** all shake parameters SHALL be visible as named constants with documented defaults

### Requirement: Vigorous oscillation pattern
The system SHALL oscillate the servo between `SHAKE_CENTER_ANGLE - SHAKE_AMPLITUDE` and `SHAKE_CENTER_ANGLE + SHAKE_AMPLITUDE` at the configured frequency. The motion SHALL use a sinusoidal or triangle wave pattern for smooth reversals.

#### Scenario: Shake at default settings
- **WHEN** the shake cycle is active with default parameters
- **THEN** the servo SHALL sweep between 55° and 125° approximately 3 times per second

#### Scenario: Smooth direction change
- **WHEN** the servo reaches the end of a sweep
- **THEN** it SHALL reverse direction without abrupt stops (smooth acceleration/deceleration)

### Requirement: Shake and rest cycle
The system SHALL alternate between shaking for `SHAKE_DURATION_S` seconds and resting for `SHAKE_REST_S` seconds. This cycle SHALL repeat indefinitely.

#### Scenario: Shake then rest
- **WHEN** the shake duration completes
- **THEN** the servo SHALL stop and rest for the configured rest period before starting the next shake cycle

#### Scenario: Continuous cycling
- **WHEN** the system is running
- **THEN** it SHALL continuously cycle between shake and rest periods without manual intervention

### Requirement: Non-blocking timing
The system SHALL use `millis()`-based timing for all shake pattern logic. The main `loop()` function SHALL NOT use `delay()` for any timing longer than 1ms.

#### Scenario: Loop remains responsive
- **WHEN** the shake pattern is running
- **THEN** the `loop()` function SHALL complete each iteration in under 5ms, allowing serial and other processing to occur

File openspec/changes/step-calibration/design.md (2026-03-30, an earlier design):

## Context

The digi-shaker counts sine wave oscillations on the ESP32 and reports them as `stepCount`. The encounter tracker uses this count to predict monster encounters at 400/450/500/550 step thresholds. However, the Digivice's physical pendulum doesn't register every oscillation -- the actual registration rate varies by shake parameters.

## Goals / Non-Goals

**Goals:**
- Calibration workflow: start shaking, enter actual Digivice steps, derive ratio
- Store multiple calibration samples per parameter configuration
- Hierarchical ratio lookup: exact config match → global average → 1.0
- Apply ratio to encounter predictions
- Settings efficiency comparison from calibration data

**Non-Goals:**
- Automatic step detection from the Digivice (requires IR reverse engineering, separate future work)
- Firmware changes (calibration is entirely backend + UI)

## Decisions

### 1. Calibration data model
**Choice:** Store each calibration sample individually with the active parameters at the time.
```sql
calibrations (
  id, created_at,
  oscillation_count, actual_steps, ratio,
  center_angle, amplitude, frequency
)
```
**Rationale:** Individual samples allow averaging, variance analysis, and per-config grouping. The ratio is stored redundantly (could be computed) for query convenience.

### 2. Ratio lookup hierarchy
**Choice:** Three-tier fallback:
1. Exact config match (center + amplitude + frequency) → average ratio from matching samples
2. No match → global average across all calibration samples
3. No calibrations → ratio = 1.0 (raw oscillation count used as-is)

**Rationale:** Users will tune parameters and then calibrate at their preferred settings. When they try new settings, the global average is a reasonable estimate until they calibrate the new config. Shake/rest duration are excluded from the config key since they don't affect step registration rate.

### 3. Calibration flow uses stepCount delta
**Choice:** Record `stepCount` at calibration start, compute delta at stop. No firmware changes.
**Rationale:** The ESP32 already tracks oscillations in `stepCount`. The browser records the value when "Start Calibration" is pressed and computes `oscillations = currentStepCount - startStepCount` when stopped. This keeps calibration entirely in the UI + backend.

### 4. Calibration state via WebSocket
**Choice:** Calibration start/stop/submit messages go through the existing WebSocket protocol. The backend stores calibrations and broadcasts updated ratio data.
**Rationale:** Consistent with the existing command relay architecture. No new HTTP endpoints needed.

### 5. Encounter tracker displays both raw and calibrated
**Choice:** Show `~87 / 120 steps` where 87 is calibrated and 120 is raw oscillations.
**Rationale:** The raw count is still useful for debugging. Showing both builds trust in the calibration and makes it obvious when the ratio is way off.

## Risks / Trade-offs

- **Calibration accuracy depends on user reading the Digivice correctly** → Show clear instructions in the UI. Multiple samples average out reading errors.
- **Config match is exact** → If the user changes center by 1 degree, it won't match previous calibrations. Acceptable because small parameter changes could genuinely affect registration rate. The global fallback handles this gracefully.
- **No auto-detection of stale calibrations** → If the physical setup changes (new cradle, different mounting), old calibrations may be wrong. User can see the history and delete bad samples if needed.

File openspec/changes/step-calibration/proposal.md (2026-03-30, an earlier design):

## Why

The encounter tracker counts sine wave oscillations as "steps," but the Digivice D3 V3's physical pendulum doesn't register every oscillation. The actual step registration rate depends on amplitude, frequency, and cradle positioning. Without calibration, encounter predictions are inaccurate -- the system might say 400 steps were taken when the Digivice only counted 290.

A calibration tool lets the user run the shaker, read the actual step count from the Digivice, and feed it back. The system derives a ratio (e.g., 72.5% of oscillations register as steps) and uses it to correct encounter predictions. Storing calibrations per parameter set also enables comparing which settings are most efficient.

## What Changes

- Add a calibration workflow to the dashboard: start calibration → shake → enter actual Digivice steps → submit
- Store calibration samples in SQLite with the active shake parameters
- Calculate per-config and global calibration ratios from stored samples
- Apply calibration ratio to encounter tracker predictions (calibrated steps = oscillations × ratio)
- Display calibrated vs raw step counts in the encounter tracker
- Show a settings efficiency comparison from calibration history

## Capabilities

### New Capabilities
- `step-calibration`: Calibration workflow, ratio storage, per-config and global ratio lookup, efficiency comparison UI

### Modified Capabilities
- `encounter-tracker`: Use calibrated step count instead of raw oscillation count for probability calculation
- `dashboard-ui`: Add calibration panel to the dashboard

## Impact

- **Backend (`dashboard/server/`)**: New `calibrations` table in SQLite, ratio lookup logic, calibration data exposed via WebSocket
- **Frontend (`dashboard/ui/`)**: New CalibrationPanel component, modified EncounterTracker to show calibrated values
- **Firmware**: No changes needed -- `stepCount` delta between start/stop provides the oscillation count

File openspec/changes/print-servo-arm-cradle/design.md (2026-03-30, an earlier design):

## Context

The digi-shaker project requires a custom mechanical arm to connect an MG996R servo to a Digivice D3 V3 Japan Edition (7.5 x 6 cm). The stock servo horn is 3.5 cm — too small to hold the device securely. A 3D-printed arm with integrated cradle is needed.

The user is new to 3D printing and will use a brother's printer. The design must be simple to print (no supports, flat on bed) and easy to assemble.

Hardware constraints:
- MG996R servo with 25-tooth spline shaft
- Digivice D3 V3: approximately 75 mm x 60 mm x 20 mm
- Vigorous shaking motion: ~60-90° sweep at 3-5 Hz
- Servo torque: 10 kg·cm — Digivice weighs ~50-80g, well within limits at 10cm arm

## Goals / Non-Goals

**Goals:**
- Parametric OpenSCAD model that generates a printable STL
- Single-piece design: arm body + cradle pocket (no assembly of printed parts)
- Mounts to MG996R via stock plastic servo horn (screwed into the arm)
- Secure pocket for Digivice with raised walls and rubber band slots
- Print-friendly: flat on bed, no supports needed, PLA compatible

**Non-Goals:**
- Servo mount/base (servo will be clamped or taped to desk/board separately)
- Electronics enclosure (ESP32 stays on breadboard)
- Printed spline fitting (too fragile in PLA — use stock horn as adapter)

## Decisions

### 1. OpenSCAD over TinkerCAD/Fusion 360
**Choice:** OpenSCAD (code-based parametric CAD)
**Rationale:** Can be generated and version-controlled as a text file. Parameters (Digivice dimensions, arm length, wall height) are easily adjustable. No GUI needed — the user's brother just opens and exports STL.
**Alternative considered:** TinkerCAD — simpler GUI but not parametric, can't version control, requires manual adjustments.

### 2. Stock servo horn as adapter
**Choice:** Screw the stock MG996R plastic servo horn to the underside of the printed arm.
**Rationale:** The 25-tooth spline is difficult to print accurately in PLA at consumer tolerances. The stock horn fits perfectly and is designed for the load. Two M2 screw holes in the arm align with the horn.
**Alternative considered:** Print spline directly — rejected due to tolerance issues and PLA brittleness at small feature sizes.

### 3. Arm length: 100mm total
**Choice:** 100mm from servo center to cradle center.
**Rationale:** At 100mm, the MG996R's 10 kg·cm torque supports ~1 kg at the tip. The Digivice weighs ~70g — this gives >10x safety margin for dynamic loads during fast shaking. Shorter arm = less leverage = more violent shake per degree of sweep.

### 4. Rubber band retention
**Choice:** Slots/notches on the cradle walls for rubber bands to hold the Digivice down.
**Rationale:** Simplest retention method. No clips or latches to design/print. Rubber bands are universally available and accommodate slight size variations. Easy to put on and remove for the user.

### 5. Dimensions with clearance
**Choice:** Cradle pocket inner dimensions: 77mm x 62mm (1mm clearance per side).
**Rationale:** 3D printers slightly over-extrude, so 1mm clearance ensures the Digivice slides in without forcing. If too loose, rubber bands handle it.

## Risks / Trade-offs

- **PLA arm flex at high frequency** → At 4mm thickness and 100mm length, PLA may flex slightly during vigorous shaking. Mitigation: user can increase infill to 40% or arm thickness parameter to 5mm if needed.
- **Servo horn screw holes misalignment** → If the printed holes don't line up perfectly with the stock horn. Mitigation: holes are slightly oversized (2.5mm for M2 screws) to allow adjustment. Can also self-tap through PLA.
- **Digivice pocket fit** → Actual device dimensions may differ slightly from spec. Mitigation: parametric design — user can adjust `digivice_width` and `digivice_length` in the .scad file and re-export.

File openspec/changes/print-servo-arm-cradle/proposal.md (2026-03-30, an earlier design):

## Why

The digi-shaker project needs a mechanical arm and cradle to hold a Digivice D3 V3 Japan Edition (7.5 x 6 cm) and attach it to an MG996R servo for vigorous shaking. The stock servo horn is only 3.5 cm — too small to securely hold the device. A custom 3D-printed arm with an integrated cradle solves this, providing a proper mount point and secure pocket for the Digivice.

## What Changes

- Add an OpenSCAD parametric 3D model for the servo arm + cradle
- The model produces a single printable part: arm body with servo horn mount on one end and a Digivice pocket on the other
- Export-ready STL file for direct slicing and printing
- Parametric design allows adjusting dimensions if measurements need tweaking

## Capabilities

### New Capabilities
- `servo-arm-model`: Parametric OpenSCAD 3D model for the MG996R servo arm with integrated Digivice D3 cradle. Generates an STL file ready for 3D printing.

### Modified Capabilities
<!-- None — this is the first change in the project -->

## Impact

- New files: `models/servo-arm-cradle.scad` (source), `models/servo-arm-cradle.stl` (export)
- No code dependencies — this is a standalone 3D model
- Required for physical assembly of the digi-shaker hardware

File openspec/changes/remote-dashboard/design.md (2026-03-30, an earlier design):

## Context

The digi-shaker is an ESP32 + MG996R servo project that shakes a Digivice D3 V3 to accumulate steps. Currently all configuration is compile-time (`config.h` constants), monitoring is serial-only, and there's no stats persistence. The user needs to tune servo parameters to reliably trigger the Digivice's physical pendulum, and wants to track shake sessions to predict monster encounters (probabilistic at 400/450/500/550 steps).

The ESP32 is on a breadboard with separate power for the servo (5V/2.4A wall charger) and USB for the ESP32. It connects to the home Wi-Fi network. A Docker-hosted dashboard on a local NUC provides the remote interface.

## Goals / Non-Goals

**Goals:**
- ESP32 connects to home Wi-Fi and accepts WebSocket commands for real-time control
- Dashboard backend (Bun + Hono) relays between browser and ESP32, persists stats in SQLite
- SolidJS dashboard UI with live status, parameter tuning, encounter prediction, and session history
- Tuning mode for precise servo calibration without shaking
- Dockerized dashboard with GitHub Actions CI
- Repository restructured with `firmware/` and `dashboard/` directories

**Non-Goals:**
- OTA firmware updates (still flash via USB)
- Multiple ESP32 device support (single shaker)
- User authentication (local network only, trusted)
- Mobile-native app (web dashboard is sufficient)
- Digivice data capture / IR communication (separate future work)
- Home Assistant or MQTT integration

## Decisions

### 1. WebSocket for ESP32 communication
**Choice:** WebSocket (not REST polling or MQTT)
**Rationale:** Parameter tuning requires sub-second round-trip: user drags a slider, servo responds immediately. WebSocket provides persistent bidirectional connection. REST polling would add latency and overhead. MQTT adds a broker dependency for no benefit with a single device.
**Library:** `WebSockets` by Links2004 -- mature, widely used ESP32 WebSocket server library.

### 2. Bun runtime with Hono framework
**Choice:** Bun as the JavaScript runtime, Hono as the web framework
**Rationale:** Bun provides native SQLite (`bun:sqlite`) eliminating the need for a separate database dependency. Hono is lightweight (~14KB), has built-in WebSocket support via `Bun.serve()`, and runs on Bun natively. This keeps the Docker image small and the dependency count low.
**Alternative considered:** Node + Express + better-sqlite3 -- works but heavier, more dependencies, and less modern.

### 3. SolidJS for the dashboard UI
**Choice:** SolidJS with TypeScript, built with Vite
**Rationale:** Fine-grained reactivity without a virtual DOM is ideal for a real-time dashboard where WebSocket messages trigger frequent UI updates. Signals map naturally to live servo state. Small bundle size (~7KB runtime). TypeScript-first.
**Alternative considered:** React -- familiar but virtual DOM overhead is wasteful for a dashboard where individual values update independently. Svelte would also work but SolidJS's JSX familiarity is a plus.

### 4. Two-hop WebSocket architecture
**Choice:** Browser ↔ Hono backend ↔ ESP32 (not browser direct to ESP32)
**Rationale:** The ESP32 has limited WebSocket capacity (2-3 concurrent connections max). The backend acts as a relay and single consumer of the ESP32 connection. It also adds persistence -- the ESP32 doesn't need to store stats across reboots. The backend can serve the dashboard even when the ESP32 is offline.
```
Browser(s) ◀──WS──▶ Hono Server ◀──WS──▶ ESP32
                         │
                     bun:sqlite
```

### 5. ESP32 as WebSocket server, backend as client
**Choice:** ESP32 runs a WebSocket server. The Hono backend connects to it as a client.
**Rationale:** The ESP32 has a known address (mDNS: `digi-shaker.local` or static IP configured in firmware). The backend initiates the connection and reconnects on drops. This is simpler than having the ESP32 know the backend's address. The ESP32 just starts its server and waits.

### 6. JSON message protocol
**Choice:** Simple JSON messages over WebSocket
**Rationale:** Human-readable, easy to debug, and the message rate is low (status updates every ~500ms, commands are sporadic). Binary protocol overhead savings are negligible at this scale.

Message types:
```
// ESP32 → Backend (state reports)
{ "type": "status", "state": "shaking"|"resting"|"tuning"|"idle", "shakeCount": 387, "angle": 122, "params": { "center": 90, "amplitude": 35, "frequency": 3.0, "shakeDuration": 30, "restDuration": 5 }, "uptimeMs": 12345678 }

// Backend → ESP32 (commands)
{ "type": "command", "action": "start"|"stop"|"tune" }
{ "type": "config", "params": { "center": 87, "amplitude": 35, "frequency": 3.0, "shakeDuration": 30, "restDuration": 5 } }
{ "type": "tune", "angle": 87 }

// Backend → Browser (relayed state + enriched data)
{ "type": "status", ...espStatus, "encounter": { "probability": 0.4, "estimatedShakesRemaining": 63 } }
{ "type": "history", "sessions": [...] }
```

### 7. Runtime parameter storage on ESP32
**Choice:** Parameters stored in RAM with compile-time defaults. No EEPROM/NVS persistence on the ESP32.
**Rationale:** The backend is the source of truth for configuration. When the ESP32 reboots, it starts with defaults from `config.h`. The backend can resend the last-used config on reconnection. This avoids EEPROM wear and keeps the firmware simple. If NVS persistence is needed later, it can be added without protocol changes.

### 8. Tuning mode state machine
**Choice:** Add `TUNING` and `IDLE` states alongside existing `SHAKING` and `RESTING`.
```
              start
  IDLE ──────────────────▶ SHAKING
   ▲                         │
   │ stop                    │ duration elapsed
   │                         ▼
   ├──────────────────── RESTING
   │                         │
   │                         │ rest elapsed
   │                         ▼
   │                      SHAKING (cycle)
   │
   │  tune
   ▼
 TUNING ─── (servo holds target angle)
   │
   │ start / stop
   ▼
 IDLE or SHAKING
```
**Rationale:** `IDLE` is the stopped state (servo detached). `TUNING` holds a specific angle for calibration. The existing `SHAKING ↔ RESTING` cycle remains unchanged. Commands can transition between states cleanly.

### 9. Encounter probability calculation
**Choice:** Backend calculates cumulative encounter probability based on shake count.
```
Steps  | Individual | Cumulative
400    | 40%        | 40%
450    | 20%        | 60%
500    | 30%        | 90%
550    | 10%        | 100%
```
**Rationale:** The ESP32 doesn't need this logic -- it just counts shakes. The backend enriches the status with encounter probability before sending to the browser. The thresholds are configurable in the backend (not hardcoded in firmware) so they can be adjusted as the user learns more about the game mechanics through reverse engineering.

### 10. Repository restructuring
**Choice:** Move firmware into `firmware/` subdirectory.
```
digi-shaker/
├── firmware/
│   ├── platformio.ini
│   ├── src/main.cpp
│   └── include/config.h
├── dashboard/
│   ├── server/
│   │   ├── index.ts
│   │   ├── db.ts
│   │   └── esp32-client.ts
│   ├── ui/
│   │   ├── src/
│   │   │   ├── App.tsx
│   │   │   ├── components/
│   │   │   └── lib/ws.ts
│   │   └── index.html
│   ├── Dockerfile
│   ├── package.json
│   └── tsconfig.json
├── .github/workflows/docker.yml
├── models/
└── openspec/
```
**Rationale:** Clean separation. PlatformIO works fine from a subdirectory (`pio run -d firmware/`). The Docker image only needs the `dashboard/` context. GitHub Actions can build the image on push to main.

### 11. Docker image strategy
**Choice:** Single-stage Bun Docker image. GitHub Actions builds and pushes to GitHub Container Registry (ghcr.io) on push to main.
**Rationale:** Bun images are small. The dashboard is a single server process serving both the API/WebSocket and the static SolidJS build. Volume mount for SQLite data persistence. Simple `docker-compose.yml` for the NUC.

```yaml
# docker-compose.yml (on NUC)
services:
  digi-shaker:
    image: ghcr.io/<user>/digi-shaker:latest
    ports:
      - "3000:3000"
    volumes:
      - ./data:/app/data
    environment:
      - ESP32_HOST=digi-shaker.local  # or IP
```

## Risks / Trade-offs

- **Wi-Fi reliability on ESP32** → The ESP32's Wi-Fi stack can be flaky under heavy servo PWM. Mitigation: WebSocket reconnection logic in the backend with exponential backoff. Status updates every 500ms act as a heartbeat.
- **mDNS resolution** → `digi-shaker.local` may not resolve reliably across all networks. Mitigation: support both mDNS and static IP configuration in the backend's environment variables.
- **ESP32 memory with WebSocket + Wi-Fi** → Wi-Fi and WebSocket server together consume significant RAM. Mitigation: limit to 1-2 concurrent WebSocket connections, keep JSON messages small, avoid string concatenation in firmware.
- **SQLite on Docker volume** → If the container is recreated without the volume mount, data is lost. Mitigation: document the volume mount clearly, include it in the example docker-compose.yml.
- **Single point of failure** → If the backend goes down, there's no way to control the shaker remotely. Mitigation: the ESP32 continues its current shake cycle autonomously. It doesn't stop just because the WebSocket disconnects. The backend is stateless enough to restart cleanly.
- **Parameter drift** → If the ESP32 reboots it loses runtime config. Mitigation: backend resends last-known config on WebSocket reconnection.

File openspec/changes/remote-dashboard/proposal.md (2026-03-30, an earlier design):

## Why

The digi-shaker currently requires serial access to monitor shake state and a firmware recompile to adjust parameters like center angle, amplitude, and frequency. Tuning the servo motion to reliably trigger the Digivice D3 V3's physical pendulum is tedious -- each adjustment means reconnecting USB, editing config.h, recompiling, and reflashing. There's also no way to track how many shakes have been performed, which matters because a monster encounter triggers at a random step count (400-550 steps) and requires manual interaction with the device.

A remote dashboard solves both problems: live parameter tuning over Wi-Fi and session/shake tracking with encounter probability estimation, so the user knows when to come back to the device.

## What Changes

- Add Wi-Fi connectivity to the ESP32 firmware with a WebSocket server for bidirectional communication
- Add a "slow/tuning" mode to the firmware where the servo moves to a target angle and holds for calibration
- Make all shake parameters runtime-configurable via WebSocket commands (no more recompile)
- Build a web dashboard (Bun + Hono backend, SolidJS frontend) that connects to the ESP32 over WebSocket
- Dashboard provides: live status, start/stop controls, parameter tuning sliders, encounter probability tracker, and session history
- Backend persists shake stats in SQLite (bun:sqlite) for historical tracking
- Dockerize the dashboard for deployment on a NUC via GitHub Actions
- Restructure the repo: move firmware into `firmware/` subdirectory, add `dashboard/` for the web app

## Capabilities

### New Capabilities
- `wifi-connectivity`: ESP32 Wi-Fi station mode, connects to home network, mDNS discovery
- `websocket-protocol`: Bidirectional WebSocket communication protocol between ESP32, backend, and browser
- `tuning-mode`: Slow servo mode for calibration -- move to target angle, hold, set as center/min/max
- `dashboard-backend`: Hono server on Bun -- relays commands between browser and ESP32, persists stats in SQLite
- `dashboard-ui`: SolidJS frontend -- status panel, tuning controls, encounter tracker, session history
- `encounter-tracker`: Shake counting with probabilistic encounter prediction (40% at 400, 20% at 450, 30% at 500, 10% at 550)
- `docker-deployment`: Dockerfile and GitHub Actions workflow for building and publishing the dashboard container

### Modified Capabilities
- `shake-patterns`: Parameters become runtime-configurable via WebSocket instead of compile-time constants. Constants in config.h become defaults that can be overridden at runtime.
- `servo-control`: Add slow/tuning mode alongside the existing shake mode. Servo accepts target angle commands for calibration.
- `serial-interface`: Serial logging remains for local debugging but is no longer the primary monitoring interface.

## Impact

- **Firmware (`firmware/src/main.cpp`, `firmware/include/config.h`)**: Major changes -- Wi-Fi stack, WebSocket server, runtime parameter storage, tuning mode state machine
- **Project structure**: Existing firmware files move from root `src/`/`include/` to `firmware/src/`/`firmware/include/`. `platformio.ini` moves to `firmware/`
- **New directory**: `dashboard/` with Hono server, SolidJS app, Dockerfile
- **New dependencies (firmware)**: WiFi.h, ESPmDNS, WebSocketsServer (or similar ESP32 WebSocket library)
- **New dependencies (dashboard)**: Bun runtime, Hono, SolidJS, Vite
- **CI/CD**: New GitHub Actions workflow for Docker image build and push
- **Network**: ESP32 needs Wi-Fi credentials (SSID/password in config), dashboard needs to know ESP32's address (mDNS or configured IP)

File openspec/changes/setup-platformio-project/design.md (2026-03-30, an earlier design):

## Context

The digi-shaker is a new ESP32 project that drives an MG996R servo to vigorously shake a Digivice D3 V3 Japan Edition. The hardware setup consists of:
- ESP32 NodeMCU (CH340, USB-C) on a 400-pin breadboard
- MG996R servo powered externally via 5V/2.4A wall charger through a cut micro-USB cable
- Servo signal on GPIO 13, common GND between ESP32 and servo
- 3D-printed arm+cradle to hold the Digivice (separate change: `print-servo-arm-cradle`)

The user chose PlatformIO over ESPHome for fine-grained control over servo motion and future reverse engineering data capture.

## Goals / Non-Goals

**Goals:**
- Working PlatformIO project that compiles and uploads to ESP32 NodeMCU
- Smooth, configurable servo shake pattern (angle, speed, frequency, duration)
- Serial output for monitoring shake state and future data capture
- Clean code structure that's easy to extend later (Wi-Fi control, data logging, IR capture)

**Non-Goals:**
- Wi-Fi or web interface (future change)
- Data capture from the Digivice (future RE work)
- OTA updates (not needed yet)
- Home Assistant integration (this isn't ESPHome)

## Decisions

### 1. Arduino framework on PlatformIO
**Choice:** Use `framework = arduino` in platformio.ini
**Rationale:** Arduino framework provides `ESP32Servo` library which handles the ESP32's LEDC PWM hardware for servo control. PlatformIO manages toolchains and dependencies cleanly. The user is familiar with this from the Enviro+ project context.
**Alternative considered:** ESP-IDF native — more control but significantly more boilerplate for a simple servo project. Not worth the complexity.

### 2. ESP32Servo library over raw LEDC PWM
**Choice:** Use the `ESP32Servo` library for servo control.
**Rationale:** ESP32 doesn't have a native Arduino `Servo.h` compatible PWM. `ESP32Servo` wraps the LEDC peripheral correctly, handles channel allocation, and provides a clean `write(angle)` API. Avoids manual microsecond pulse math.
**Alternative considered:** Raw LEDC — full control but requires manual pulse width calculation (500-2400µs mapping) and channel management. Unnecessary complexity.

### 3. GPIO 13 for servo signal
**Choice:** Use GPIO 13 for the servo PWM signal.
**Rationale:** GPIO 13 is PWM-capable, has no boot-mode side effects (unlike GPIO 0, 2, 12, 15), and is easily accessible on the NodeMCU DevKit. It doesn't conflict with I2C (21/22), SPI, or UART pins that might be used for future sensor additions.

### 4. Shake pattern as configurable constants
**Choice:** Define shake parameters as `constexpr` values in a config header, not hardcoded in the loop.
**Rationale:** Easy to tune without reading through motion logic. Parameters: sweep angle (degrees), shake frequency (Hz), shake duration (seconds), rest duration (seconds). Later these become Wi-Fi-configurable.

### 5. Non-blocking motion with millis()
**Choice:** Use `millis()`-based timing instead of `delay()` for shake motion.
**Rationale:** `delay()` blocks the entire loop — no serial processing, no future button handling, no Wi-Fi. A non-blocking approach using millis() allows the shake pattern to run while still processing serial input and future features.

### 6. Project structure
```
digi-shaker/
├── platformio.ini          # Build config
├── include/
│   └── config.h            # Shake parameters
├── src/
│   └── main.cpp            # Entry point, setup/loop
├── lib/                    # Future local libraries
├── models/                 # 3D print files (other change)
└── openspec/               # Specs (existing)
```

## Risks / Trade-offs

- **Servo jitter at extreme speeds** → The MG996R is analog, not digital. At very high oscillation frequencies (>5Hz), it may not reach target angles before reversing. Mitigation: start with conservative 3Hz, tune up based on Digivice response.
- **ESP32 brownout from shared USB power** → If the servo draws a spike through shared ground, the ESP32 may brownout-reset. Mitigation: separate power supplies (wall charger for servo, USB for ESP32). Add a 100µF capacitor across servo power if resets occur.
- **MG996R pulse range varies by unit** → Not all MG996R servos have identical pulse ranges. The ESP32Servo library defaults may not map to full 0-180° range. Mitigation: expose `min_pulse_us` and `max_pulse_us` as config parameters for calibration.

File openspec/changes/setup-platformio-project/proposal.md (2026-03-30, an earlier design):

## Why

The digi-shaker needs firmware to drive an MG996R servo in a vigorous shaking pattern to simulate walking/running motion for a Digivice D3 V3 Japan Edition. This is the foundation for an automated shaking rig that will later support data capture for reverse engineering the device. PlatformIO on ESP32 provides fine-grained control over servo timing, motion patterns, and future extensibility (Wi-Fi control, data logging).

## What Changes

- Initialize a PlatformIO project targeting ESP32 NodeMCU (CH340, USB-C)
- Configure the build environment for the ESP32 DevKit with Arduino framework
- Implement servo control using hardware PWM on GPIO 13
- Create a configurable shake pattern: sweep angle, frequency, duration, and pause intervals
- Add serial monitor output for debugging and future data capture
- Wire the complete hardware setup: ESP32 on 400-pin breadboard, MG996R powered by 5V/2.4A wall charger via cut micro-USB cable

## Capabilities

### New Capabilities
- `servo-control`: Hardware PWM servo control for MG996R on ESP32, including initialization, angle setting, and safe detach
- `shake-patterns`: Configurable shaking motion patterns with adjustable sweep angle, frequency, duration, and rest intervals
- `serial-interface`: Serial monitor output for status reporting, shake counting, and future reverse engineering data capture

### Modified Capabilities
<!-- None — this is the first firmware in the project -->

## Impact

- New PlatformIO project structure: `platformio.ini`, `src/main.cpp`, `include/`, `lib/`
- Dependencies: Arduino framework, ESP32Servo library
- Hardware: ESP32 GPIO 13 drives servo signal; 5V/2.4A external power for servo; common GND between ESP32 and servo
- Future: serial interface becomes the data pipeline for RE work

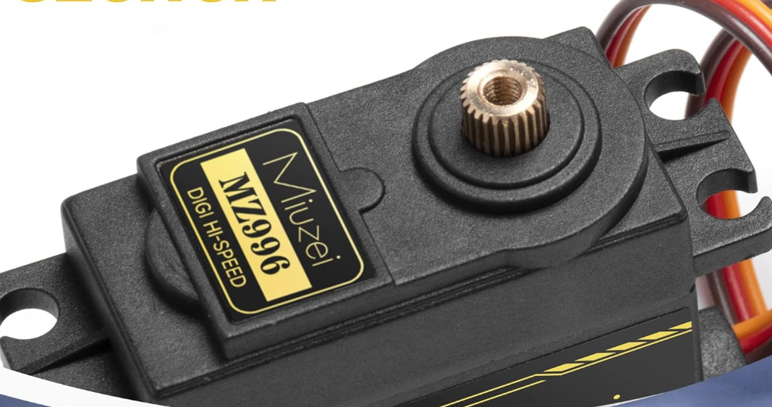
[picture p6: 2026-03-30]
images/servo.png

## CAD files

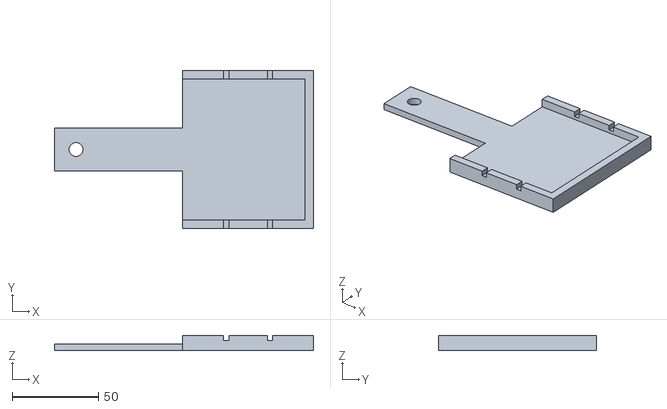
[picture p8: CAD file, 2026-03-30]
models/servo-arm-cradle-v2.stl
150.5 x 92.0 x 9.00

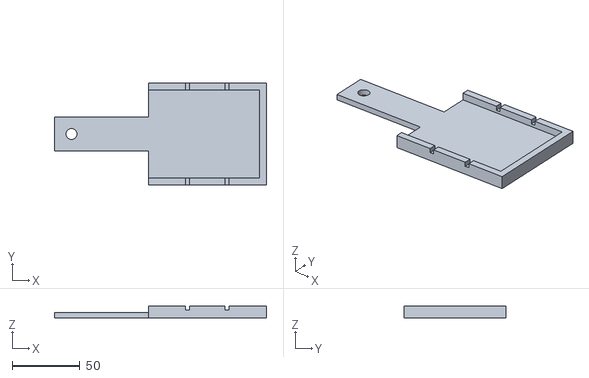
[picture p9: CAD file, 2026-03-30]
models/servo-arm-cradle.stl
156.0 x 75.0 x 9.00

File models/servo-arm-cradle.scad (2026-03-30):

// ============================================================
// Digi-Shaker: Servo Arm + Digivice Cradle
// ============================================================
// Parametric 3D model for MG996R servo arm with integrated
// cradle for Digivice D3 V3 Japan Edition.
//
// The Digivice lies FLAT in the cradle, rotated so its long
// axis (top-to-bottom) runs ACROSS the arm. This way, the
// up-and-down servo swing applies force along the device's
// length, matching how a pedometer detects steps.
//
// Usage:
//   1. Adjust parameters below to fit your device
//   2. Press F5 to preview
//   3. Press F6 to render
//   4. Export as STL (File > Export as STL)
//
// Print settings: PLA, 0.2mm layer height, 20-30% infill,
// no supports needed (prints flat on bed)
// ============================================================

// --- Digivice dimensions (mm) ---
digivice_height    = 80;   // Top-to-bottom (long axis) → becomes cradle WIDTH
digivice_width     = 64;   // Left-to-right (short axis) → becomes cradle LENGTH (along arm)

// --- Clearance ---
clearance = 1;             // Gap per side for easy fit

// --- Arm dimensions ---
arm_length    = 100;       // Servo center to cradle center
arm_width     = 25;        // Width of the arm beam
arm_thickness = 4;         // Thickness of the base plate

// --- Cradle walls ---
wall_height    = 5;        // How high walls rise above arm surface
wall_thickness = 5;        // Wall thickness

// --- Servo horn mount ---
horn_center_hole = 8.0;    // Center hole for servo center screw clearance

// --- Rubber band slots ---
band_slot_width = 3;       // Width of each U-notch
band_slot_depth = 3;       // Depth of each U-notch

// ============================================================
// Derived dimensions
// ============================================================

e = 0.01;  // Epsilon for clean boolean operations

// Cradle pocket: Digivice rotated 90° so height runs across arm (Y)
// and width runs along arm (X)
pocket_along_arm = digivice_width + 2 * clearance;   // 65mm (along X)
pocket_across_arm = digivice_height + 2 * clearance;  // 77mm (along Y)

cradle_outer_length = pocket_along_arm + 2 * wall_thickness;   // X direction
cradle_outer_width  = pocket_across_arm + 2 * wall_thickness;  // Y direction

total_height = arm_thickness + wall_height;

servo_mount_length = arm_width;
beam_length = arm_length - servo_mount_length / 2 - cradle_outer_length / 2;

// Where the cradle starts on the X axis
cradle_x = servo_mount_length + beam_length;
// Y offset to center the cradle on the arm
cradle_y = (arm_width - cradle_outer_width) / 2;

// ============================================================
// Dimension readout (printed to console on F5/F6)
// ============================================================

echo(str("=== Dimensions ==="));
echo(str("Total length (along arm): ", cradle_x + cradle_outer_length, " mm"));
echo(str("Cradle outer width (across arm): ", cradle_outer_width, " mm"));
echo(str("Cradle pocket: ", pocket_along_arm, " x ", pocket_across_arm, " mm"));
echo(str("Total height: ", total_height, " mm"));
echo(str("Arm beam length: ", beam_length, " mm"));

// ============================================================
// Single solid body with all cuts applied at once
// ============================================================

difference() {
    // --- Positive geometry ---
    union() {
        // Servo mount plate + arm beam as one continuous slab
        cube([cradle_x + e, arm_width, arm_thickness]);

        // Cradle solid block (overlaps beam by epsilon)
        translate([cradle_x - e, cradle_y, 0])
            cube([cradle_outer_length + e, cradle_outer_width, total_height]);
    }

    // --- Negative geometry (all cuts) ---

    // Center hole for servo center screw clearance
    translate([servo_mount_length/2, arm_width/2, -e])
        cylinder(h = arm_thickness + 2*e, d = horn_center_hole, $fn = 36);

    // Cradle pocket interior (open on one short side for device insertion)
    // Open on the X-min side (toward servo) so device slides in from the arm side
    translate([cradle_x - 2*e, cradle_y + wall_thickness, arm_thickness])
        cube([cradle_outer_length - wall_thickness + 3*e,
              pocket_across_arm,
              wall_height + e]);

    // --- Rubber band slots on long walls (Y-min and Y-max) ---
    // These walls run along the Digivice's height (the long axis)

    // Left long wall (Y-min side)
    for (i = [0 : 1]) {
        slot_x = cradle_x + cradle_outer_length * (i + 1) / 3 - band_slot_width / 2;
        translate([slot_x, cradle_y - e, total_height - band_slot_depth])
            cube([band_slot_width, wall_thickness + 2*e, band_slot_depth + e]);
    }

    // Right long wall (Y-max side)
    for (i = [0 : 1]) {
        slot_x = cradle_x + cradle_outer_length * (i + 1) / 3 - band_slot_width / 2;
        translate([slot_x, cradle_y + cradle_outer_width - wall_thickness - e, total_height - band_slot_depth])
            cube([band_slot_width, wall_thickness + 2*e, band_slot_depth + e]);
    }
}

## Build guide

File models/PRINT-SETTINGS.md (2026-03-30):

# Print Settings for servo-arm-cradle.stl

## Recommended Settings

| Setting | Value |
|---|---|
| Material | PLA |
| Layer height | 0.2mm |
| Infill | 20-30% |
| Supports | None needed |
| Bed adhesion | Brim (optional, helps with long flat parts) |
| Orientation | Flat side down (as exported) |

## Estimated print time
30-45 minutes depending on printer speed.

## Assembly

1. Screw the stock MG996R servo horn onto the servo shaft
2. Place the printed arm on top of the horn, aligning the two screw holes
3. Screw through the arm into the horn using the small screws from the MG996R kit
4. Slide the Digivice into the cradle from the open end
5. Wrap rubber bands through the wall notches to secure the device

## Adjustments

If the fit is too tight or too loose, edit `servo-arm-cradle.scad` in OpenSCAD:
- `clearance` — increase for looser fit, decrease for tighter (default: 1mm)
- `wall_height` — increase if the device bounces out during shaking
- `arm_thickness` — increase to 5mm if the arm flexes too much

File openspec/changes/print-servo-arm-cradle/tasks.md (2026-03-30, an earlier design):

## 1. Project Setup

- [x] 1.1 Create `models/` directory in the project root
- [x] 1.2 Install OpenSCAD (or confirm it's available) for STL export

## 2. OpenSCAD Model

- [x] 2.1 Create `models/servo-arm-cradle.scad` with all parametric variables at the top (digivice dimensions, arm length, wall height, clearance, horn screw spacing)
- [x] 2.2 Model the arm body: flat rectangular bar, 100mm x 25mm x 4mm
- [x] 2.3 Model the servo horn mount: flat area with two 2.5mm through-holes spaced 10mm apart on one end
- [x] 2.4 Model the cradle pocket: rectangular walls (77mm x 62mm inner) rising 5mm, with one short side open for device insertion
- [x] 2.5 Model rubber band retention slots: at least two U-shaped notches (3mm wide, 3mm deep) on top edge of each long wall
- [x] 2.6 Verify the model renders correctly in OpenSCAD preview (F5)

## 3. STL Export

- [x] 3.1 Render the final model in OpenSCAD (F6) and export as `models/servo-arm-cradle.stl`
- [ ] 3.2 Verify the STL is manifold and error-free (import into a slicer to confirm)

## 4. Documentation

- [x] 4.1 Add print settings note to the models directory (PLA, 0.2mm layer height, 20-30% infill, no supports)

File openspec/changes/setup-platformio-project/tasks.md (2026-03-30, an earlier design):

## 1. PlatformIO Project Setup

- [x] 1.1 Initialize PlatformIO project with `platformio.ini` targeting `esp32dev` board with Arduino framework
- [x] 1.2 Add `ESP32Servo` library dependency to `platformio.ini`
- [x] 1.3 Set serial monitor speed to 115200 in `platformio.ini`
- [x] 1.4 Add `.gitignore` for PlatformIO build artifacts (`.pio/`, `.vscode/`)

## 2. Configuration

- [x] 2.1 Create `include/config.h` with all shake parameters (center angle, amplitude, frequency, duration, rest time)
- [x] 2.2 Add servo pulse width config (min_pulse_us, max_pulse_us) with MG996R defaults
- [x] 2.3 Add GPIO pin definition (SERVO_PIN = 13)

## 3. Servo Control

- [x] 3.1 Implement servo initialization in `src/main.cpp` setup() — attach to GPIO 13 with configurable pulse range, move to center
- [x] 3.2 Implement angle-setting function with clamping to 0-180° range
- [x] 3.3 Implement servo detach for rest periods

## 4. Shake Pattern

- [x] 4.1 Implement non-blocking shake oscillation using millis() and sinusoidal wave for smooth motion
- [x] 4.2 Implement shake/rest cycle state machine (SHAKING → RESTING → SHAKING)
- [x] 4.3 Implement shake cycle counter

## 5. Serial Interface

- [x] 5.1 Print startup message with project name and all configured parameters
- [x] 5.2 Print status messages on shake start and rest start with cycle count
- [x] 5.3 Print total shake count on each rest transition

## 6. Hardware Wiring & Testing

- [ ] 6.1 Wire ESP32 on breadboard: servo signal (GPIO 13), common GND, external 5V from cut micro-USB cable to servo power
- [ ] 6.2 Upload firmware, verify servo sweeps correctly via serial monitor
- [ ] 6.3 Tune shake parameters (amplitude, frequency) based on Digivice response

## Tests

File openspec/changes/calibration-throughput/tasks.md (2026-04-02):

## 1. Backend - Database & Duration Storage

- [x] 1.1 Add `shaking_duration_s REAL` nullable column to `calibrations` table
- [x] 1.2 Update `insertCalibration()` to accept optional `shakingDurationS` parameter
- [x] 1.3 Add throughput computation to `getCalibrationHistory()` — measured when duration available, computed from config params when not

## 2. Backend - Calibration Tracking

- [x] 2.1 Add per-client calibration state tracking (`Map<ws, CalibrationState>`) in `index.ts`
- [x] 2.2 Handle `startCalibration` message: initialize tracking state for the client
- [x] 2.3 Accumulate shaking time on ESP32 status updates: track `shaking` state transitions for active calibrations
- [x] 2.4 Handle `stopCalibration` message: finalize duration, respond with `calibrationStopped` including `shakingDurationS`
- [x] 2.5 Clean up calibration state on WebSocket disconnect
- [x] 2.6 Update `calibration` submit handler to pass `shakingDurationS` to `insertCalibration()`

## 3. Frontend - Protocol & State

- [x] 3.1 Add `startCalibration` / `stopCalibration` send helpers and `calibrationStopped` handler to `ws.ts`
- [x] 3.2 Add throughput fields to `ConfigEfficiency` type and `CalibrationData` types
- [x] 3.3 Store tracked `shakingDurationS` from `calibrationStopped` response for submit

## 4. Frontend - UI Updates

- [x] 4.1 Update `CalibrationPanel` to send `startCalibration`/`stopCalibration` messages and include duration on submit
- [x] 4.2 Update Settings Efficiency table to display throughput (steps/min) as primary metric, sort by throughput descending
- [x] 4.3 Show efficiency as secondary metric alongside throughput in each config row

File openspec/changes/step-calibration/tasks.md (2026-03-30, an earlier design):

## 1. Backend - Database & Ratio Logic

- [x] 1.1 Add `calibrations` table to SQLite schema in `db.ts`
- [x] 1.2 Add `insertCalibration(oscillationCount, actualSteps, centerAngle, amplitude, frequency)` function
- [x] 1.3 Add `deleteCalibration(id)` function
- [x] 1.4 Add `getCalibrationRatio(centerAngle, amplitude, frequency)` function with three-tier fallback
- [x] 1.5 Add `getCalibrationHistory()` function returning per-config grouped samples with averages

## 2. Backend - WebSocket Integration

- [x] 2.1 Handle `calibration` message type: store sample using current ESP32 params, respond with updated ratio
- [x] 2.2 Handle `getCalibration` message type: respond with current ratio and efficiency breakdown
- [x] 2.3 Handle `deleteCalibration` message type: delete sample, respond with updated ratio
- [x] 2.4 Include `calibrationRatio` and `calibratedStepCount` in enriched status messages to browsers

## 3. Frontend - Calibration Panel

- [x] 3.1 Create `CalibrationPanel.tsx` with start/stop calibration flow tracking stepCount delta
- [x] 3.2 Add actual steps input with validation and submit button
- [x] 3.3 Display current ratio with source indicator (config-specific vs global vs uncalibrated)
- [x] 3.4 Display settings efficiency comparison table sorted by efficiency
- [x] 3.5 Add expandable sample history per config with delete buttons
- [x] 3.6 Add calibration panel to App.tsx layout

## 4. Frontend - Encounter Tracker Update

- [x] 4.1 Update `ws.ts` types to include `calibrationRatio` and `calibratedStepCount` in status
- [x] 4.2 Update EncounterTracker to use `calibratedStepCount` for probability calculation
- [x] 4.3 Display both calibrated and raw step counts when ratio is not 1.0

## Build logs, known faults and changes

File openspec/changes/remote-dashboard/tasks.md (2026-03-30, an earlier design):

## 1. Repository Restructuring

- [x] 1.1 Move `platformio.ini`, `src/`, `include/`, `lib/`, `test/` into `firmware/` subdirectory
- [x] 1.2 Update any PlatformIO paths or configs to work from `firmware/` directory
- [x] 1.3 Create `dashboard/` directory with `package.json` (Bun + Hono + SolidJS + Vite)
- [x] 1.4 Add `include/wifi_credentials.h` to `.gitignore` and create `include/wifi_credentials.example.h` template

## 2. ESP32 Wi-Fi & mDNS

- [x] 2.1 Add Wi-Fi station mode initialization to firmware: connect to SSID/password from `wifi_credentials.h`, retry on failure
- [x] 2.2 Add mDNS registration (`digi-shaker.local`) after successful Wi-Fi connection
- [x] 2.3 Add Wi-Fi status logging to serial (IP address, connection/disconnection events)
- [x] 2.4 Add Wi-Fi reconnection logic that does not interrupt active shake cycles

## 3. ESP32 WebSocket Server

- [x] 3.1 Add WebSockets library dependency to `platformio.ini`
- [x] 3.2 Initialize WebSocket server on port 81 after Wi-Fi connects
- [x] 3.3 Implement periodic status message broadcast (JSON, every 500ms) with state, shake count, angle, params, uptime
- [x] 3.4 Implement command message parsing: start, stop, tune, resetCount
- [x] 3.5 Implement config update message parsing: update runtime shake parameters
- [x] 3.6 Implement tune angle message: move servo to target angle in TUNING state
- [x] 3.7 Add WebSocket event logging to serial (connect/disconnect/command received)
- [x] 3.8 Add invalid message handling (malformed JSON, unknown types)

## 4. ESP32 State Machine Refactor

- [x] 4.1 Extend state enum to IDLE, SHAKING, RESTING, TUNING
- [x] 4.2 Implement IDLE state: servo centered and detached, waiting for commands
- [x] 4.3 Implement TUNING state: slow servo movement to target angle (1 degree per 20ms), hold position
- [x] 4.4 Implement state transitions: start→SHAKING, stop→IDLE, tune→TUNING from any state
- [x] 4.5 Refactor shake parameters from compile-time constants to runtime variables with config.h defaults
- [x] 4.6 Implement shake counter reset command
- [x] 4.7 Remove the DEBUG_ANGLE serial logging (replaced by WebSocket status reporting)

## 5. Dashboard Backend

- [x] 5.1 Set up Hono server with Bun, listening on configurable port (default 3000)
- [x] 5.2 Implement ESP32 WebSocket client: connect to `ESP32_HOST:81`, reconnect with exponential backoff
- [x] 5.3 Implement browser WebSocket endpoint at `/ws`: accept connections, relay ESP32 status
- [x] 5.4 Implement command relay: forward browser commands to ESP32, return error if ESP32 disconnected
- [x] 5.5 Implement status enrichment: calculate encounter probability from shake count, append to status messages
- [x] 5.6 Set up SQLite database with `bun:sqlite`: schema for sessions, encounters, and config
- [x] 5.7 Implement session recording: log shake cycles with timestamps, counts, duration, parameters
- [x] 5.8 Implement encounter recording: log counter resets with timestamp and shake count
- [x] 5.9 Implement history query endpoint: sessions grouped by day
- [x] 5.10 Implement last-known config persistence and resend on ESP32 reconnection
- [x] 5.11 Configure Hono to serve static SolidJS build files

## 6. Dashboard UI - Setup & Layout

- [x] 6.1 Initialize SolidJS project with Vite and TypeScript in `dashboard/ui/`
- [x] 6.2 Create WebSocket client module (`lib/ws.ts`): connect to backend, expose reactive signals for status
- [x] 6.3 Create App layout with header (title + connection indicator) and main content panels

## 7. Dashboard UI - Status & Controls

- [x] 7.1 Build connection status indicator component (green/yellow/red)
- [x] 7.2 Build status panel: current state, cycle count, uptime
- [x] 7.3 Build start/stop control buttons
- [x] 7.4 Build counter reset button ("Monster encountered")

## 8. Dashboard UI - Parameter Tuning

- [x] 8.1 Build parameter slider components for: center angle, amplitude, frequency, shake duration, rest duration
- [x] 8.2 Wire sliders to send config updates via WebSocket with debounced sending (< 100ms)
- [x] 8.3 Build tuning mode toggle and target angle slider
- [x] 8.4 Build "Set as center" / "Set as min" / "Set as max" buttons in tuning mode
- [x] 8.5 Build "Test shake" button in tuning mode
- [x] 8.6 Display live current angle readout

## 9. Dashboard UI - Encounter Tracker

- [x] 9.1 Build encounter probability display with cumulative probability calculation (0%/40%/60%/90%/100%)
- [x] 9.2 Build progress bar with visual urgency colors (neutral → warning → alert)
- [x] 9.3 Build estimated shakes remaining display
- [x] 9.4 Build estimated time remaining display (based on shake frequency and duration params)

## 10. Dashboard UI - Session History

- [x] 10.1 Build history panel with daily session summaries
- [x] 10.2 Display encounter markers in history (when monster was encountered, at what shake count)

## 11. Docker & CI

- [x] 11.1 Create `dashboard/Dockerfile`: Bun base image, build SolidJS, run Hono server
- [x] 11.2 Create `docker-compose.example.yml` with port mapping, volume mount, and ESP32_HOST env var
- [x] 11.3 Create GitHub Actions workflow: build Docker image on push to main, push to ghcr.io with `latest` and commit SHA tags

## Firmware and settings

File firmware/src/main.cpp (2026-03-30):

#include <Arduino.h>
#include <WiFi.h>
#include <ESPmDNS.h>
#include <ESP32Servo.h>
#include <WebSocketsServer.h>
#include <ArduinoJson.h>
#include "config.h"
#include "wifi_credentials.h"

// --- State machine ---
enum ShakeState { IDLE, SHAKING, RESTING, TUNING };

ShakeState state = IDLE;
unsigned long stateStartMs = 0;
unsigned long stepCount = 0;
unsigned long cycleCount = 0;
int lastSinSign = 0; // tracks zero-crossings for step counting

// --- Runtime parameters (defaults from config.h) ---
int centerAngle = DEFAULT_CENTER_ANGLE;
int amplitude = DEFAULT_AMPLITUDE;
float frequencyHz = DEFAULT_FREQUENCY_HZ;
int shakeDurationS = DEFAULT_SHAKE_DURATION_S;
int restDurationS = DEFAULT_REST_DURATION_S;

// --- Servo ---
Servo servo;
int currentAngle = 0;

// --- Tuning ---
int tuneTargetAngle = DEFAULT_CENTER_ANGLE;
int tuneCurrentAngle = DEFAULT_CENTER_ANGLE;
unsigned long lastTuneStepMs = 0;

// --- WebSocket ---
WebSocketsServer ws(WS_PORT);
unsigned long lastStatusMs = 0;

// --- Wi-Fi ---
unsigned long lastWifiCheckMs = 0;
constexpr unsigned long WIFI_RETRY_MS = 5000;

// ============================================================
// Servo helpers
// ============================================================

void setServoAngle(int angle) {
    if (angle < 0) angle = 0;
    if (angle > 180) angle = 180;
    currentAngle = angle;
    servo.write(angle);
}

void attachServo() {
    servo.attach(SERVO_PIN, MIN_PULSE_US, MAX_PULSE_US);
}

void detachServo() {
    servo.detach();
}

// ============================================================
// State transitions
// ============================================================

void enterIdle() {
    state = IDLE;
    setServoAngle(centerAngle);
    delay(50);
    detachServo();
    Serial.println("[STATE] IDLE");
}

void enterShaking() {
    state = SHAKING;
    stateStartMs = millis();
    attachServo();
    lastSinSign = 0;
    cycleCount++;
    Serial.print("[SHAKE] Cycle #");
    Serial.print(cycleCount);
    Serial.print(" (steps: ");
    Serial.print(stepCount);
    Serial.print(") started at ");
    Serial.print(millis() / 1000);
    Serial.println("s");
}

void enterResting() {
    state = RESTING;
    stateStartMs = millis();
    setServoAngle(centerAngle);
    delay(50);
    detachServo();
    Serial.print("[REST] Resting. Steps: ");
    Serial.print(stepCount);
    Serial.print(" Cycles: ");
    Serial.println(cycleCount);
}

void enterTuning() {
    state = TUNING;
    attachServo();
    tuneCurrentAngle = currentAngle;
    tuneTargetAngle = currentAngle;
    lastTuneStepMs = millis();
    Serial.println("[STATE] TUNING");
}

// ============================================================
// WebSocket: build & send status JSON
// ============================================================

void broadcastStatus() {
    JsonDocument doc;
    doc["type"] = "status";

    switch (state) {
        case IDLE:    doc["state"] = "idle"; break;
        case SHAKING: doc["state"] = "shaking"; break;
        case RESTING: doc["state"] = "resting"; break;
        case TUNING:  doc["state"] = "tuning"; break;
    }

    doc["stepCount"] = stepCount;
    doc["cycleCount"] = cycleCount;
    doc["angle"] = currentAngle;
    doc["uptimeMs"] = millis();

    JsonObject params = doc["params"].to<JsonObject>();
    params["center"] = centerAngle;
    params["amplitude"] = amplitude;
    params["frequency"] = frequencyHz;
    params["shakeDuration"] = shakeDurationS;
    params["restDuration"] = restDurationS;

    String json;
    serializeJson(doc, json);
    ws.broadcastTXT(json);
}

// ============================================================
// WebSocket: handle incoming messages
// ============================================================

void handleMessage(uint8_t clientNum, const String& payload) {
    JsonDocument doc;
    DeserializationError err = deserializeJson(doc, payload);
    if (err) {
        Serial.print("[WS] Bad JSON: ");
        Serial.println(err.c_str());
        return;
    }

    const char* type = doc["type"];
    if (!type) return;

    if (strcmp(type, "command") == 0) {
        const char* action = doc["action"];
        if (!action) return;

        Serial.print("[WS] Command: ");
        Serial.println(action);

        if (strcmp(action, "start") == 0) {
            enterShaking();
        } else if (strcmp(action, "stop") == 0) {
            enterIdle();
        } else if (strcmp(action, "tune") == 0) {
            enterTuning();
        } else if (strcmp(action, "resetCount") == 0) {
            stepCount = 0;
            cycleCount = 0;
            Serial.println("[WS] Counters reset");
        }

    } else if (strcmp(type, "config") == 0) {
        JsonObject params = doc["params"];
        if (params.isNull()) return;

        if (params["center"].is<int>())        centerAngle    = params["center"];
        if (params["amplitude"].is<int>())     amplitude      = params["amplitude"];
        if (params["frequency"].is<float>())   frequencyHz    = params["frequency"];
        if (params["shakeDuration"].is<int>()) shakeDurationS = params["shakeDuration"];
        if (params["restDuration"].is<int>())  restDurationS  = params["restDuration"];

        Serial.print("[WS] Config updated: center=");
        Serial.print(centerAngle);
        Serial.print(" amp=");
        Serial.print(amplitude);
        Serial.print(" freq=");
        Serial.println(frequencyHz);

    } else if (strcmp(type, "tune") == 0) {
        if (state == TUNING && doc["angle"].is<int>()) {
            tuneTargetAngle = doc["angle"];
            if (tuneTargetAngle < 0) tuneTargetAngle = 0;
            if (tuneTargetAngle > 180) tuneTargetAngle = 180;
            Serial.print("[TUNE] Target: ");
            Serial.println(tuneTargetAngle);
        }
    }
}

void onWebSocketEvent(uint8_t clientNum, WStype_t type, uint8_t* payload, size_t length) {
    switch (type) {
        case WStype_CONNECTED:
            Serial.print("[WS] Client #");
            Serial.print(clientNum);
            Serial.println(" connected");
            break;
        case WStype_DISCONNECTED:
            Serial.print("[WS] Client #");
            Serial.print(clientNum);
            Serial.println(" disconnected");
            break;
        case WStype_TEXT:
            handleMessage(clientNum, String((char*)payload));
            break;
        default:
            break;
    }
}

// ============================================================
// Wi-Fi
// ============================================================

void connectWifi() {
    Serial.print("[WIFI] Connecting to ");
    Serial.println(WIFI_SSID);

    WiFi.mode(WIFI_STA);
    WiFi.begin(WIFI_SSID, WIFI_PASSWORD);

    unsigned long start = millis();
    while (WiFi.status() != WL_CONNECTED && millis() - start < 10000) {
        delay(250);
        Serial.print(".");
    }
    Serial.println();

    if (WiFi.status() == WL_CONNECTED) {
        Serial.print("[WIFI] Connected! IP: ");
        Serial.println(WiFi.localIP());

        if (MDNS.begin("digi-shaker")) {
            Serial.println("[MDNS] Registered as digi-shaker.local");
        }
    } else {
        Serial.println("[WIFI] Connection failed, will retry");
    }
}

// ============================================================
// Setup & Loop
// ============================================================

void setup() {
    Serial.begin(115200);
    delay(500);

    Serial.println("=== Digi-Shaker ===");
    Serial.print("Servo pin: GPIO ");
    Serial.println(SERVO_PIN);
    Serial.print("Default center: ");
    Serial.print(DEFAULT_CENTER_ANGLE);
    Serial.print(" amp: ");
    Serial.print(DEFAULT_AMPLITUDE);
    Serial.print(" freq: ");
    Serial.println(DEFAULT_FREQUENCY_HZ);
    Serial.println("===================");

    // Init servo to center then detach (start IDLE)
    attachServo();
    setServoAngle(centerAngle);
    delay(500);
    detachServo();

    connectWifi();

    ws.begin();
    ws.onEvent(onWebSocketEvent);
    Serial.print("[WS] Server started on port ");
    Serial.println(WS_PORT);
}

void loop() {
    unsigned long now = millis();

    // Wi-Fi reconnection
    if (WiFi.status() != WL_CONNECTED && now - lastWifiCheckMs >= WIFI_RETRY_MS) {
        lastWifiCheckMs = now;
        Serial.println("[WIFI] Reconnecting...");
        WiFi.reconnect();
    }

    // WebSocket tick
    ws.loop();

    // Periodic status broadcast
    if (now - lastStatusMs >= STATUS_INTERVAL_MS) {
        lastStatusMs = now;
        broadcastStatus();
    }

    // State machine
    unsigned long elapsed = now - stateStartMs;

    switch (state) {
        case IDLE:
            // Do nothing, wait for commands
            break;

        case SHAKING: {
            if (elapsed >= (unsigned long)shakeDurationS * 1000UL) {
                enterResting();
                break;
            }
            float t = elapsed / 1000.0f;
            float sinVal = sin(2.0f * PI * frequencyHz * t);
            float angle = centerAngle + amplitude * sinVal;
            setServoAngle((int)angle);

            // Count steps: each positive zero-crossing = 1 oscillation = 1 step
            int sinSign = (sinVal >= 0) ? 1 : -1;
            if (lastSinSign < 0 && sinSign >= 0) {
                stepCount++;
            }
            lastSinSign = sinSign;
            break;
        }

        case RESTING:
            if (elapsed >= (unsigned long)restDurationS * 1000UL) {
                enterShaking();
            }
            break;

        case TUNING:
            if (tuneCurrentAngle != tuneTargetAngle && now - lastTuneStepMs >= TUNE_STEP_MS) {
                lastTuneStepMs = now;
                if (tuneCurrentAngle < tuneTargetAngle) tuneCurrentAngle++;
                else tuneCurrentAngle--;
                setServoAngle(tuneCurrentAngle);
            }
            break;
    }
}

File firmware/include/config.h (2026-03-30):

#pragma once

// --- GPIO ---
constexpr int SERVO_PIN = 13;

// --- Servo pulse width (MG996R defaults) ---
constexpr int MIN_PULSE_US = 500;
constexpr int MAX_PULSE_US = 2400;

// --- Shake parameter defaults (overridable at runtime via WebSocket) ---
constexpr int DEFAULT_CENTER_ANGLE = 60;
constexpr int DEFAULT_AMPLITUDE = 60;
constexpr float DEFAULT_FREQUENCY_HZ = 4.0f;
constexpr int DEFAULT_SHAKE_DURATION_S = 30;
constexpr int DEFAULT_REST_DURATION_S = 5;

// --- WebSocket ---
constexpr int WS_PORT = 81;
constexpr unsigned long STATUS_INTERVAL_MS = 500;

// --- Tuning ---
constexpr unsigned long TUNE_STEP_MS = 20;

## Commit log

2026-03-30 Initial commit: ESP32 digi-shaker with remote dashboard
    Firmware: ESP32 servo shaker with Wi-Fi, WebSocket server, 4-state
    machine (idle/shaking/resting/tuning), runtime-configurable params,
    and mDNS discovery.
    Dashboard: Bun + Hono backend relaying WebSocket between browser and
    ESP32, SolidJS UI with live status, parameter tuning sliders,
    calibration mode, encounter probability tracker, and session history.
    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
    [servo-arm-cradle-v2.stl, servo-arm-cradle.scad, servo-arm-cradle.stl]
2026-03-30 Fix step counting and add toast feedback
    Count individual oscillations (sine wave zero-crossings) as steps
    instead of counting shake cycles. The encounter tracker now uses
    stepCount which matches actual Digivice pedometer behavior.
    Add toast notifications for button actions (start/stop/reset) and
    connection state changes to give clear feedback on what's happening.
    [main.cpp]
2026-03-30 Add step calibration tool for accurate encounter prediction
    Calibration workflow: start shaking, enter actual Digivice step count,
    system derives a registration ratio. Supports multiple samples and
    per-config ratios with three-tier fallback (config → global → 1.0).
    Settings efficiency comparison shows which parameter configurations
    register the most steps. Encounter tracker now uses calibrated step
    count for probability calculations, displaying both raw and calibrated.
2026-04-02 Add throughput tracking to calibration for time-based config comparison
    Track shaking duration (excluding rest/idle) during calibration runs so
    configs can be compared by steps/minute throughput, not just efficiency
    ratio. Existing data uses computed throughput as fallback. Settings
    efficiency table now sorts by throughput with efficiency shown alongside.
